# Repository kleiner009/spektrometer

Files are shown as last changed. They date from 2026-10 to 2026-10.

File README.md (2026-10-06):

# Spektrometer für Leuchtmittel

Ein Demo-Spektrometer für den Unterricht, gebaut aus einem Raspberry Pi 5, einer Monochrom-Kamera ohne IR-Filter und einem Taschenspektroskop. Es zeigt das Spektrum von Glühlampe, Leuchtstofflampe und LEDs live auf einem Touchdisplay und auf dem Beamer und berechnet **Farbwiedergabeindex Ra, R9 und Farbtemperatur**.

Entstanden für den Lernfeld-Unterricht „Beleuchtungstechnik“ (Elektroniker/-in für Betriebstechnik): Lichtfarbe, Farbwiedergabe, Unterschied zwischen Kolorimeter und Spektralphotometer.

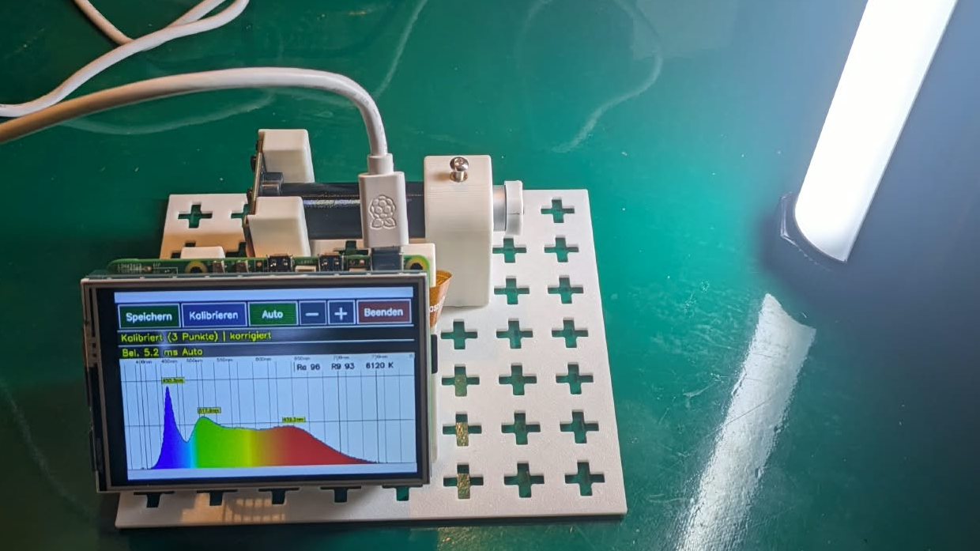
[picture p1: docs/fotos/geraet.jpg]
Spektrometer mit Raspberry Pi 5, Touchdisplay und Taschenspektroskop zeigt das Spektrum einer LED


| Draufsicht | Spaltkappe (Streuscheibe) |
|---|---|
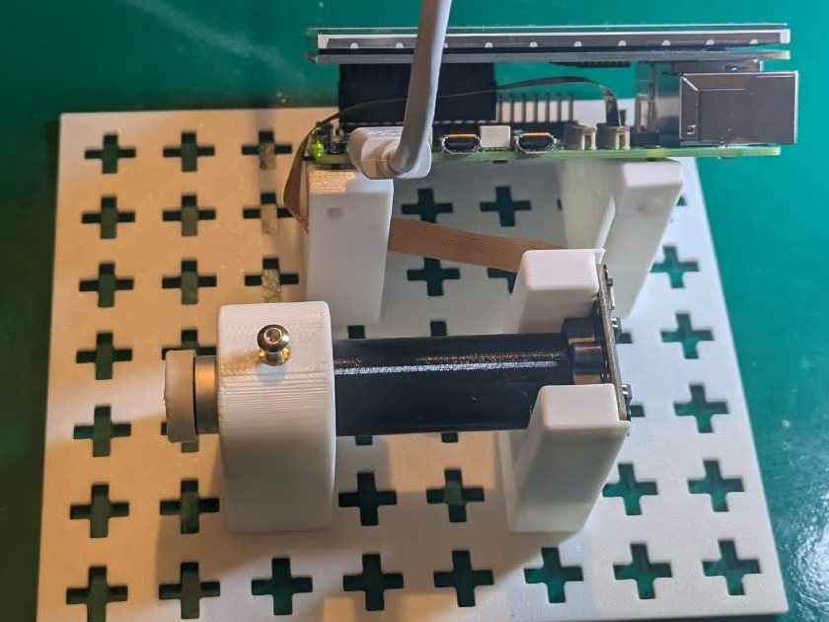
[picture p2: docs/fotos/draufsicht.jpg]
Draufsicht: Spektroskop, Kamera und Raspberry Pi auf der Grundplatte
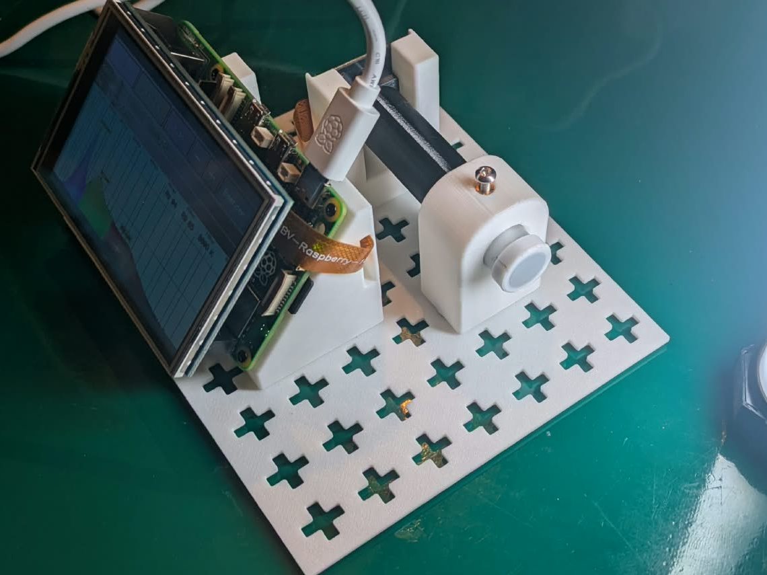
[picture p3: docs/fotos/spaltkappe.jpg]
Weiße Spaltkappe vor dem Taschenspektroskop
|  |  |

## Funktionen

- **Live-Spektrum 360–800 nm**, farbig dargestellt, mit den drei stärksten Maxima
- **Ra, R9 und Farbtemperatur** nach CIE 13.3 (über [colour-science](https://www.colour-science.org/)), als Schätzwert gekennzeichnet
- **Empfindlichkeitskorrektur** mit einer Glühlampe als Referenz (Planck-Strahler)
- **Kalibrier-Assistent** am Touchdisplay mit zwei Methoden für die Wellenlängen: **Leuchtstofflampe** (6 Linien automatisch erkannt, ± 1 nm) oder **Laser + LED**; danach Glühlampe für die Empfindlichkeit
- **Beamer-Ansicht** in Full HD: öffnet sich automatisch, sobald HDMI angesteckt wird
- Belichtung automatisch oder von Hand (0,1 ms bis 1 s), Speichern auf USB-Stick (PNG mit Datum und Maxima)
- Autostart, Bedienung komplett per Touch

## So funktioniert es

```
Lampe → Spaltkappe mit Streuscheibe → Taschenspektroskop (Prisma) → M12-Objektiv → Kamera OV9281 → Raspberry Pi 5
```

Die Streuscheibe vor dem Spalt sorgt dafür, dass Helligkeit und Lage des Spektrums nicht von der Lampenposition abhängen. Die Kamera fotografiert das Spektrum durch das Okular. Das Programm wertet die Kamerazeilen aus, ordnet jeder Spalte eine Wellenlänge zu und korrigiert die Empfindlichkeit des Aufbaus.

**Technische Besonderheiten:**
- Das Messprofil kommt aus den **Sensor-Rohdaten (10 Bit)**, nicht aus dem fertigen Kamerabild. Die Bildverarbeitung des Pi (Farbmatrix, Rauschfilter, Randabschattungs-Korrektur) ist bei schwachen Signalen stark nichtlinear.
- Über **60 Sensorzeilen** gemittelt, das senkt das Rauschen.
- Die Glühlampen-Referenz wird **zweimal belichtet** (kurz für Rot, lang für Blau) und zusammengesetzt, weil eine Glühlampe im Blauen nur wenige Prozent ihrer Rot-Intensität hat.
- **Ohne IR-Sperrfilter** reicht der Messbereich bis über 780 nm (mit Filter endet er bei ≈ 650 nm).

## Wie genau ist das?

Für Vergleiche im Unterricht gut geeignet, **kein Messgerät** im Sinne einer Prüfung.

| Lichtquelle | Nennwert | gemessen | Ra |
|---|---|---|---|
| Energiesparlampe Philips Genie 18 W warmweiß | 2700 K | 2659 K | 84 |
| LED-Lampe | 5500 K | 5509 K | 79 |

Stand 06.10.2026, Kalibrierung mit Leuchtstofflampe. Die Bilder unten stammen noch von der Laser-Kalibrierung (04.10.).

| Glühlampe | LED 5000 K | LED 8500 K |
|---|---|---|
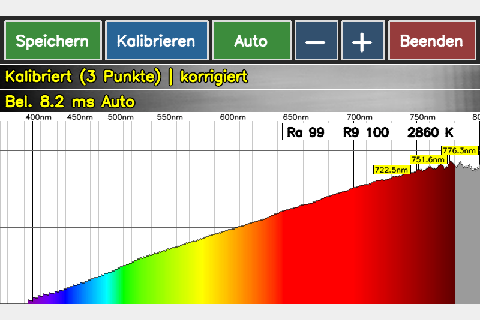
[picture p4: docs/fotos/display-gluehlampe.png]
Spektrum Glühlampe
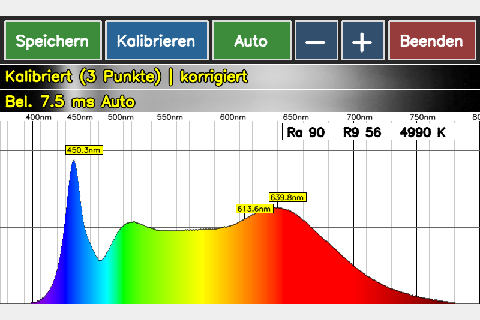
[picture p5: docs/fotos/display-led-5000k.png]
Spektrum LED 5000 K
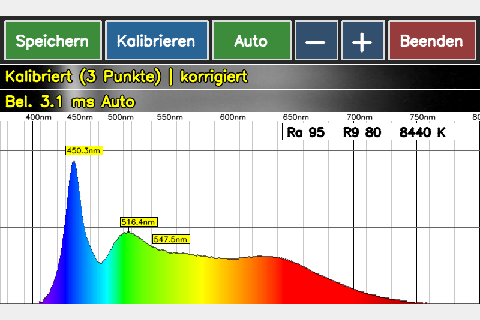
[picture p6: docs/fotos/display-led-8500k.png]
Spektrum LED 8500 K
|  |  |  |

**Beamer-Ansicht (Full HD):**

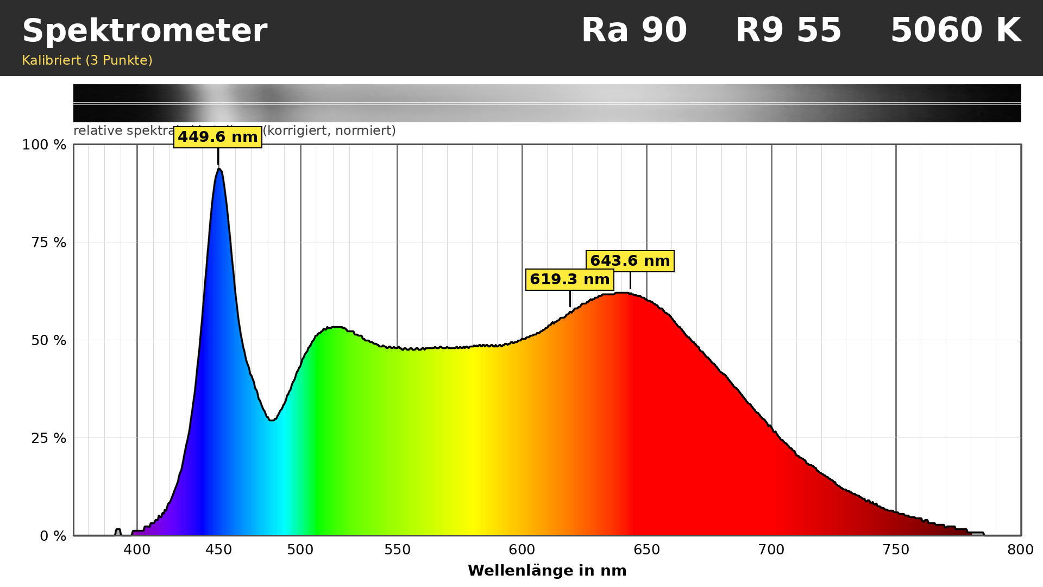
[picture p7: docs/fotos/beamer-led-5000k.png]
Beamer-Ansicht mit dem Spektrum einer 5000-K-LED


- Wellenlängenauflösung: einige Nanometer (Taschenspektroskop + Kamera)
- **Wellenlängen:** Mit der Leuchtstofflampe liegen alle 6 Linien (405–709 nm) auf ± 1,1 nm. Unterhalb 405 nm und oberhalb 710 nm wird extrapoliert.
- **Laser-Wellenlängen nie ungeprüft annehmen:** Unser „532-nm“-Laser lag laut Leuchtstofflampe bei ≈ 513 nm (Diodenlaser). Mit der falschen Annahme zeigte das Gerät im Grün/Gelb bis zu 20 nm daneben.
- **Temperatur der Referenz-Glühlampe:** Sie ist meist unbekannt und bestimmt die ganze Empfindlichkeitskorrektur. Unsere 200-W-Lampe strahlt wie ≈ 2060 K (Abgleich: Energiesparlampe 2700 K und LED 5500 K stimmen damit beide auf ≈ 2 %). Mit den üblichen 2850 K zeigte das Gerät die LED bei fast 30 000 K. Voreinstellung: `GLUEHLAMPE_K` in `software/kalibrierung.py`; bei einer anderen Lampe mit einer Lampe bekannter Farbtemperatur prüfen.
- **Kein Tageslicht** bei der Glühlampen-Messung: Fremdlicht vom Fenster verfälscht die Korrektur stark.
- **Winkel beachten:** Viele LED-Leuchten strahlen je nach Richtung unterschiedliches Licht ab (bei der 8500-K-Leuchte schwankte die Anzeige zwischen ≈ 8500 und über 13 000 K). Lampen für Vergleiche immer gleich ausrichten.

## Nachbauen

1. **Teile besorgen:** siehe [KAUFLISTE.md](KAUFLISTE.md)
2. **Drucken:** Grundplatte, Halter und Spaltkappe, siehe [hardware/](hardware/)
3. **Raspberry Pi OS installieren** (64 Bit, mit Desktop, Trixie oder Bookworm), SSH/WLAN nach Bedarf
4. **Software installieren:**
   ```bash
   git clone https://github.com/kleiner009/spektrometer.git
   cd spektrometer
   ./install.sh
   sudo reboot
   ```
   Das Skript installiert die Pakete, legt `~/Spektrometer` mit einer Python-Umgebung an, trägt nach Rückfrage Kamera und Display in `/boot/firmware/config.txt` ein und richtet Autostart, Fensterregeln, Bildschirmprofile und eine Desktop-Verknüpfung ein.
5. **Touch kalibrieren** (falls nötig): `software/touch_kalibrierung.py` liefert die Matrix für `~/.config/labwc/rc.xml`
6. **Kalibrieren** (siehe unten)

## Kalibrieren

Taste **„Kalibrieren“** am Display. Zuerst wird die Methode für die Wellenlängen gewählt.

**Leuchtstofflampe (empfohlen, 5 Schritte):**

1. **Bildausschnitt:** Weißes Licht vor den Spalt, der grüne Rahmen markiert das Spektrum, dann „Übernehmen“.
2. **Leuchtstofflampe:** Energiesparlampe (Dreibanden-Leuchtstoff) ≥ 3 min vorher einschalten und vor den Spalt stellen, „Messen“. Der Assistent belichtet kurz und lang, erkennt die Linien Hg 405/436, Tb 488, Hg 546, Eu 611/709 nm selbst, prüft die Spiegelung und zeigt den Restfehler je Linie (gut: ≤ 1,5 nm).
3. **Kontrolle (optional):** Laser vor den Spalt; angezeigt wird nur, welche Wellenlänge die neue Achse ihm gibt.
4. **Glühlampe** (siehe unten), 5. **Speichern.**

**Laser + LED (6 Schritte):** 1 Bildausschnitt · 2 grüner Laser · 3 roter Laser · 4 Blauspitze einer weißen LED (optional) · 5 Glühlampe · 6 Speichern. Die Laser-Wellenlängen sind am Gerät einstellbar; Voreinstellung `LASER_GRUEN_NM`/`LASER_ROT_NM` in `software/kalibrierung.py`.

**Glühlampe:** klare Glühlampe ohne Dimmer, 15–20 cm Abstand, **Rollo zu**. Die Belichtung wird für zwei Messungen automatisch gewählt. „Übereinstimmung lang/kurz“ sollte zwischen 0,8 und 1,25 liegen. Die Farbtemperatur der Lampe ist mit − / + einstellbar (siehe „Wie genau ist das?“).

Gespeichert wird erst im letzten Schritt, die alten Werte werden in `alt/` gesichert.

Nach den Wellenlängen-Schritten **schneidet der Assistent den Bildausschnitt automatisch zu**: Schritt 1 wählt den Rahmen bewusst großzügig, danach wird der Ausschnitt so angepasst, dass 360–800 nm die volle Displaybreite füllen. Die Glühlampe wird bereits im endgültigen Ausschnitt gemessen. (`software/zuschnitt.py` bleibt als Werkzeug für ältere Kalibrierungen.)

## Bedienung

| Taste | Funktion |
|---|---|
| Speichern | PNG des Diagramms (mit Datum und Maxima) auf den USB-Stick |
| Kalibrieren | startet den Kalibrier-Assistenten |
| Auto/Manuell | automatische Belichtung an/aus |
| − / + | Belichtung in Stufen (0,1 ms … 1 s) |
| Beenden | Programm beenden |

Grau gezeichnete Kurventeile liegen außerhalb des kalibrierten Bereichs und gehen nicht in Ra/R9/Farbtemperatur ein.

## Ordner

```
software/   Programm (spektrometer.py, kamera.py, kalibrierung.py, beamer.py, …)
system/     Vorlagen: labwc-Fensterregeln/Touch, kanshi-Bildschirmprofile
hardware/   Druckdateien (3MF, Fusion 360 f3d) und Aufbauhinweise
install.sh  Installation auf dem Raspberry Pi
```

**Unterstützte Kameras:** OV9281 Mono (empfohlen) und OV5647 (Farbe; nur sinnvoll ohne IR-Sperrfilter in Objektiv *und* Halter). Das Modell wird automatisch erkannt (`kamera.py`, Tabelle `SENSOREN`).

## Sicherheit im Unterricht

- **Leuchtstofflampe:** enthält Quecksilber; bei Bruch lüften und Scherben nicht mit dem Staubsauger aufnehmen.
- **Laser:** nur Laserklasse 1 oder 2 (< 1 mW), nie in Augen oder auf spiegelnde Flächen richten.
- **Glühlampe:** wird heiß; Abstand halten, Halter aus PETG (nicht PLA) drucken.

## Lizenz und Dank

Apache License 2.0, siehe [LICENSE](LICENSE) und [NOTICE](NOTICE).

Die Software baut auf **[PySpectrometer2](https://github.com/leswright1977/PySpectrometer2) von Les Wright** auf (Apache-2.0). Geänderte Dateien tragen einen Änderungshinweis im Kopf.

Projektseite: [johannes-roeding.de/spektrometer](https://johannes-roeding.de/spektrometer)

---

*Werbehinweis: Die Kaufliste enthält Amazon-Partnerlinks (mit \* markiert). Als Amazon-Partner verdiene ich an qualifizierten Verkäufen.*

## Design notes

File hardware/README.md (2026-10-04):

# Hardware

## Druckdateien (`druckdateien/`)

| Datei | Inhalt |
|---|---|
| `Spektrometer_01-Grundplatte.3mf` | Grundplatte, trägt alle Halter |
| `Spektrometer_01-Halter-Spektroskop.3mf` | Halter für das Taschenspektroskop |
| `Spektrometer_01-Kamerahalter.3mf` | Halter für die Kamera OV9281 mit M12-Objektiv |
| `Spektrometer_01-RasPi-Halter.3mf` | Halter für den Raspberry Pi 5 mit Display |
| `Spektrometer_01-Spaltkappe.3mf` | Spaltkappe mit Aufnahme für die Streuscheibe |
| `Spektrometer_01-Tunnel.3mf` | Lichttunnel zwischen Lampe und Spaltkappe |
| `Spektrometer_01-All.3mf` | alle Teile zusammen auf einer Druckplatte |
| `Spektrometer_01-All.f3d` | Fusion-360-Konstruktion aller Teile (zum Anpassen, z. B. für eine andere Kamera) |

## Stückliste Kleinteile

| Teil | Anzahl |
|---|---|
| Gewindeeinsatz M3 (z. B. ruthex RX-M3x5.7) | 9 |
| Gewindeeinsatz M2 (z. B. ruthex RX-M2x4) | 8 |
| Senkkopfschraube M3 × 10, Innensechskant | 8 |
| Linsen-/Pilzkopfschraube M3 × 12, Innensechskant | 1 |
| Linsenkopfschraube M2 × 10, Innensechskant | 8 |

Die Gewindeeinsätze werden mit dem Lötkolben eingeschmolzen. Bezugsquellen siehe [KAUFLISTE.md](../KAUFLISTE.md).

**Druckeinstellungen:** PETG schwarz matt (wärmefest wegen der Glühlampe, streulichtarm), Schichthöhe 0,2 mm, mindestens 3 Wände, Füllung ≥ 30 %.

**Ausnahme Spaltkappe:** aus **weißem PLA** auf einer **glatten, unstrukturierten Druckplatte** drucken, **erste Schicht 0,1 mm**. Die Kappe wirkt als Streuscheibe vor dem Spalt und muss das Licht gleichmäßig durchlassen. Eine strukturierte Platte oder eine dickere erste Schicht verschlechtern das. PLA wird ab etwa 55 °C weich, deshalb die Glühlampe beim Kalibrieren nicht direkt an die Kappe halten.

## Hinweise zum Aufbau

- **Streuscheibe vor dem Spalt ist Pflicht.** Ohne sie hängen Helligkeit und Lage des Spektrums stark von der Lampenposition ab.
- **Kamera mittig und dicht vor das Okular** setzen und auf das Spektrum scharfstellen.
- **Kamerakabel zugentlasten.** Ein gelöstes Flachbandkabel zeigt sich als „Camera frontend has timed out“.
- **Streulicht vermeiden:** Fällt Licht am Spektroskop vorbei auf die Kamera, erscheint im Bild ein heller Fleck neben dem Spektrum und verfälscht die Messung. Übergang Spektroskop → Kamera abdunkeln.

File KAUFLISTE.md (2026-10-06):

# Kaufliste

Genau diese Teile stecken im Original-Aufbau. Preise schwanken (Stand: 06.10.2026).

> **Werbehinweis:** Die mit \* markierten Links sind Amazon-Partnerlinks (Werbelinks). Als Amazon-Partner verdiene ich an qualifizierten Verkäufen. Für dich ändert sich der Preis dadurch nicht.

## Elektronik

| Teil | Hinweis | ca. € | Link |
|---|---|---|---|
| Raspberry Pi 5 (2 GB) Starter-Set | enthält Netzteil 27 W, 64-GB-microSD, Micro-HDMI-Kabel und Kühlung; das Gehäuse wird nicht gebraucht | 138 | [Amazon\*](https://www.amazon.de/dp/B0DV2F9R16?tag=johannesroe08-21) |
| Touchdisplay 3,5" (AZDelivery, 480 × 320, ILI9486 + XPT2046) | **5er-Pack**; zum Stand 04.10.2026 nicht lieferbar, gleichwertige Displays über die Suche | – | [Amazon\*](https://www.amazon.de/dp/B0CN9L2TBY?tag=johannesroe08-21) · [Suche\*](https://www.amazon.de/s?k=3%2C5+Zoll+Touch+Display+Raspberry+Pi+480x320&tag=johannesroe08-21) |
| Kamera innomaker OV9281 Mono, Global Shutter | **inklusive Objektiv, ohne IR-Sperrfilter**; kein zusätzliches Objektiv nötig | 30 | [Amazon\*](https://www.amazon.de/dp/B09WTP5GZH?tag=johannesroe08-21) |
| USB-Stick | optional, zum Speichern der Messungen | 6 | [Amazon\*](https://www.amazon.de/s?k=USB+Stick+16GB&tag=johannesroe08-21) |

## Optik und Kalibrierung

| Teil | Hinweis | ca. € | Link |
|---|---|---|---|
| Taschenspektroskop 55 mm („Juwelier-Spektroskop“) | Geradsicht-Prismenspektroskop mit Spalt | 36 | [Amazon\*](https://www.amazon.de/dp/B0788TLD1T?tag=johannesroe08-21) |
| Energiesparlampe Philips Genie 18 W E27, warmweiß | **Wellenlängen-Kalibrierung** (Linien 405–709 nm); jede Dreibanden-Energiesparlampe geht | 8 | [Amazon\*](https://www.amazon.de/dp/B0094DY2CG?tag=johannesroe08-21) |
| Laserpointer grün | optional (Methode „Laser + LED“ oder Kontrolle). **Wellenlänge prüfen:** unser „532-nm“-Laser hatte ≈ 513 nm. **Nur Laserklasse 1/2 (< 1 mW)**, nie in Augen richten | 10 | [Amazon\*](https://www.amazon.de/s?k=Laserpointer+gr%C3%BCn+532nm+Klasse+2&tag=johannesroe08-21) |
| Laserpointer rot, 650 nm | optional, ebenfalls Klasse 1/2 | 8 | [Amazon\*](https://www.amazon.de/s?k=Laserpointer+rot+650nm+Klasse+2&tag=johannesroe08-21) |
| Glühlampe 100–200 W, klar, E27 + Fassung | Referenz für die Empfindlichkeitskorrektur; ohne Dimmer betreiben; Farbtemperatur mit einer bekannten Lampe abgleichen | 5–10 | [Amazon\*](https://www.amazon.de/s?k=Gl%C3%BChbirne+100W+E27+klar&tag=johannesroe08-21) |
| Weiße LED (z. B. Handylicht) | nur Methode „Laser + LED“: Blauspitze ≈ 450 nm | – | vorhanden |

## Mechanik (3D-Druck)

| Teil | Bedarf | Packung | ca. € | Link |
|---|---|---|---|---|
| PLA-Filament weiß, 1,75 mm | nur für die Spaltkappe (Streuscheibe) | 1 kg | 20 | [Amazon\*](https://www.amazon.de/s?k=PLA+Filament+wei%C3%9F+1%2C75&tag=johannesroe08-21) |
| PETG-Filament schwarz, matt, 1,75 mm | laut Slicer | 1 kg | 20 | [Amazon\*](https://www.amazon.de/s?k=PETG+Filament+schwarz+matt+1%2C75&tag=johannesroe08-21) |
| Gewindeeinsatz M3 (ruthex RX-M3x5.7) | **9 Stück** | 100 | 9 | [Amazon\*](https://www.amazon.de/dp/B08BCRZZS3?tag=johannesroe08-21) |
| Gewindeeinsatz M2 (ruthex RX-M2x4) | **8 Stück** | 70 | 9 | [Amazon\*](https://www.amazon.de/dp/B088QJG676?tag=johannesroe08-21) |
| Senkkopfschraube M3 × 10, Innensechskant | **8 Stück** | 50 | 5 | [Amazon\*](https://www.amazon.de/dp/B0GDY545LD?tag=johannesroe08-21) |
| Linsen-/Pilzkopfschraube M3 × 12, Innensechskant | **1 Stück** | 70 | 6 | [Amazon\*](https://www.amazon.de/dp/B0FW4H74J7?tag=johannesroe08-21) |
| Linsenkopfschraube M2 × 10, Innensechskant | **8 Stück** | 50 | 8 | [Amazon\*](https://www.amazon.de/dp/B01E5EOLJC?tag=johannesroe08-21) |

**Gesamt:** rund 290 € ohne Display und ohne bereits Vorhandenes (Drucker, Werkzeug, Lötkolben zum Einschmelzen der Gewindeeinsätze). Von Schrauben und Einsätzen bleibt reichlich übrig.

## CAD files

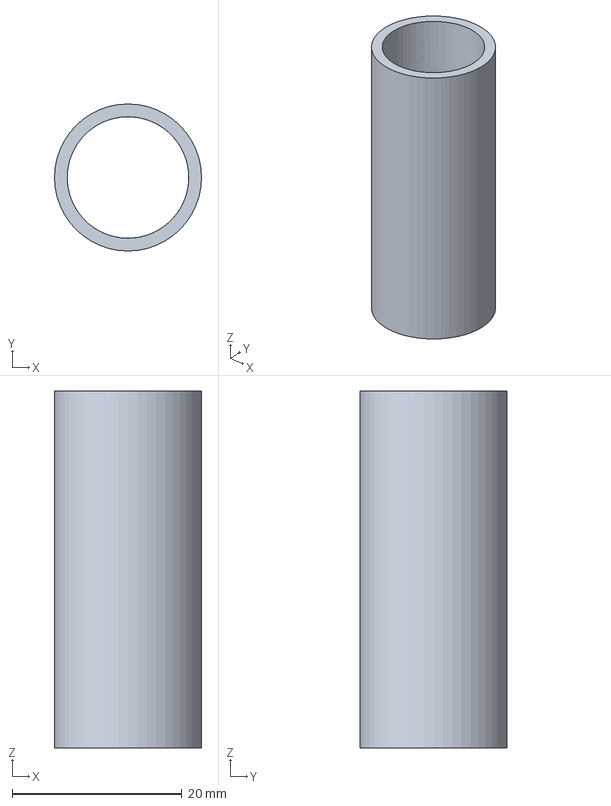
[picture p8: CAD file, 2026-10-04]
hardware/druckdateien/Spektrometer_01-Tunnel.3mf
17.3 x 17.3 x 42.0 mm

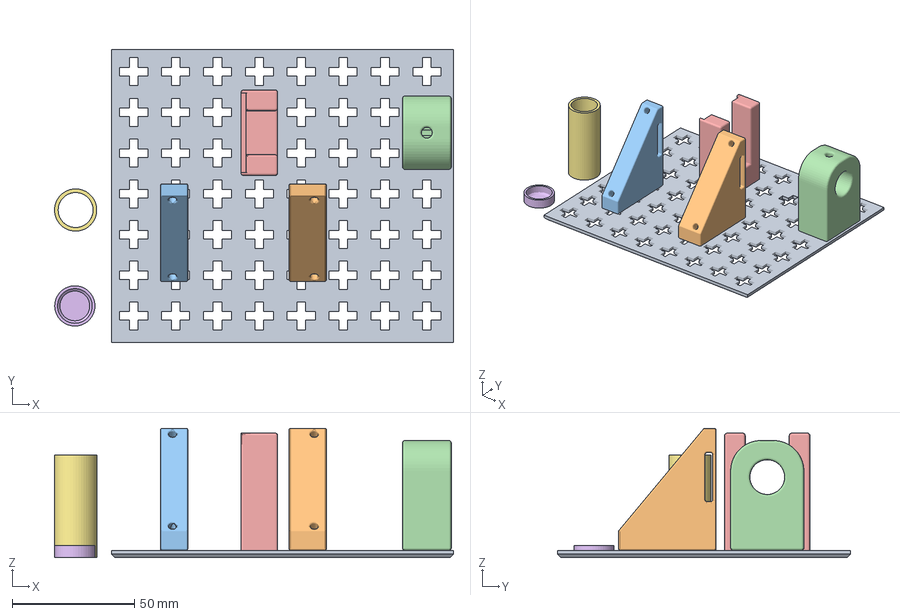
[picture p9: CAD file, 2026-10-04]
hardware/druckdateien/Spektrometer_01-All.3mf
163.3 x 120.0 x 53.0 mm
Körper3
Körper4
Körper5
Körper6
Körper7
Körper8
Körper9

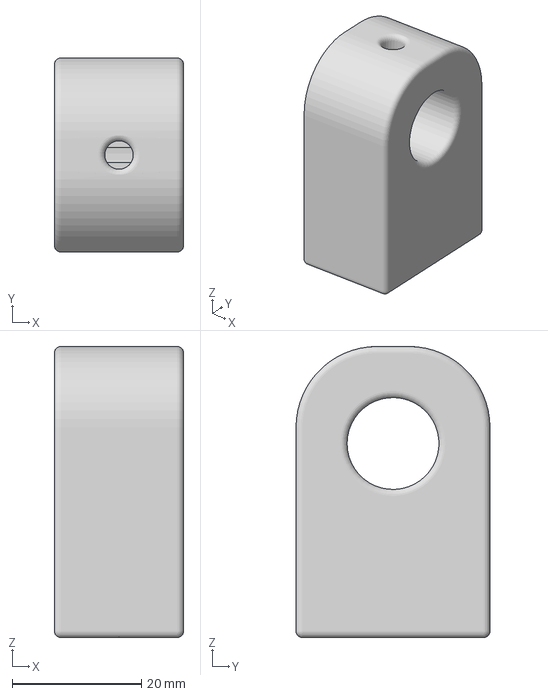
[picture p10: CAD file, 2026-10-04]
hardware/druckdateien/Spektrometer_01-Halter-Spektroskop.3mf
20.0 x 30.0 x 45.0 mm

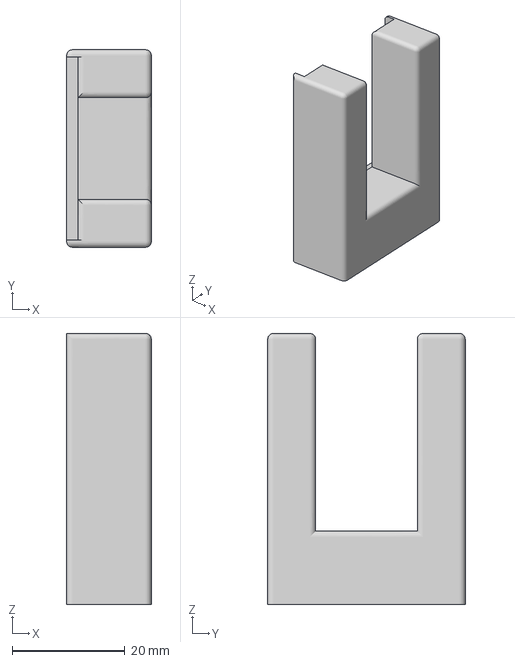
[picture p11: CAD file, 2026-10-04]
hardware/druckdateien/Spektrometer_01-Kamerahalter.3mf
15.0 x 35.0 x 48.0 mm

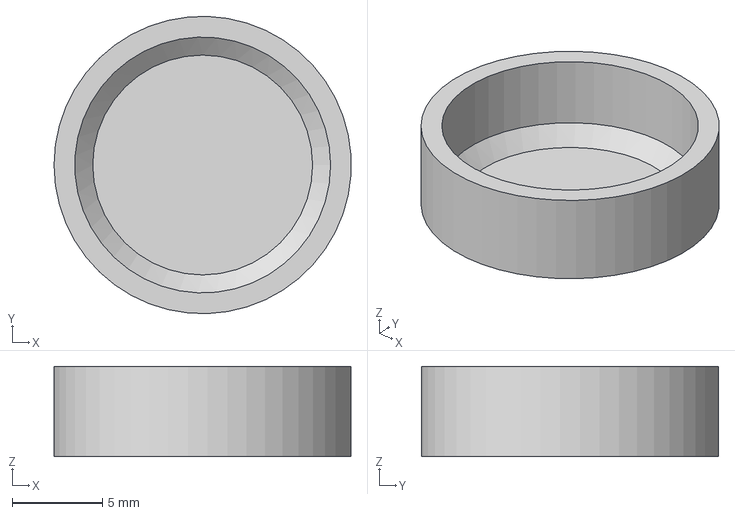
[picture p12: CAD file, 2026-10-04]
hardware/druckdateien/Spektrometer_01-Spaltkappe.3mf
16.5 x 16.5 x 5.00 mm

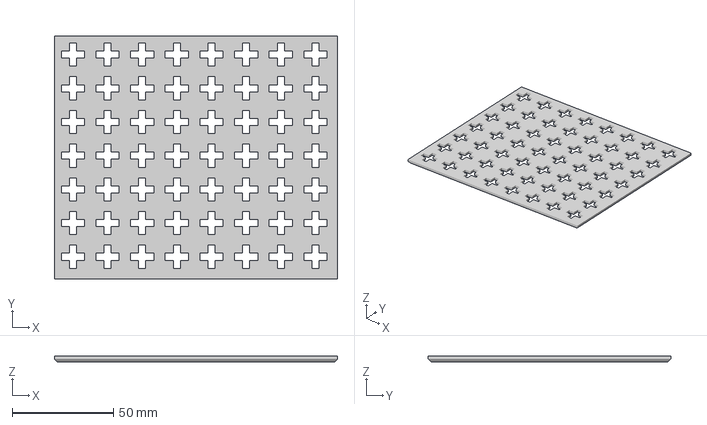
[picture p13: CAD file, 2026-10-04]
hardware/druckdateien/Spektrometer_01-Grundplatte.3mf
140.0 x 120.0 x 3.00 mm

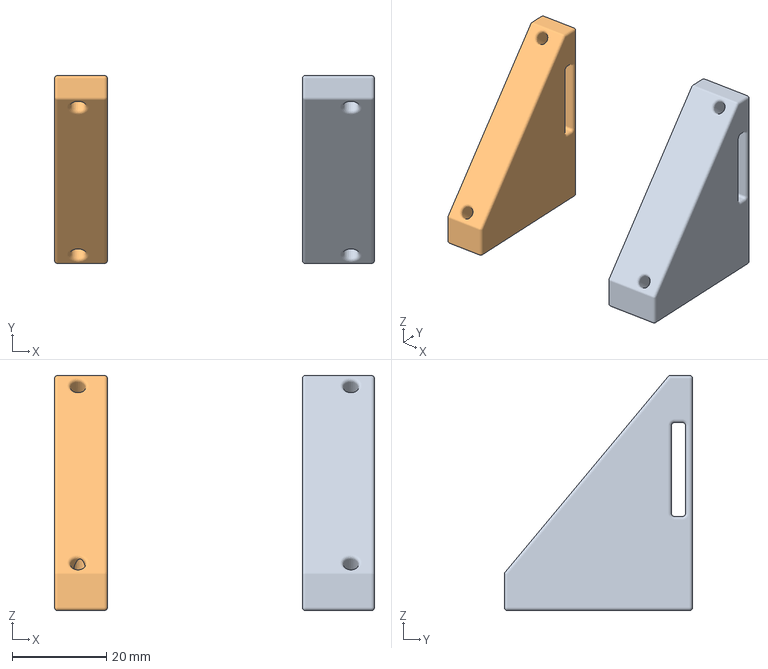
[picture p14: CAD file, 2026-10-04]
hardware/druckdateien/Spektrometer_01-RasPi-Halter.3mf
68.0 x 40.0 x 50.0 mm
Körper4
Körper5

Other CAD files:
hardware/druckdateien/Spektrometer_01-All.f3d

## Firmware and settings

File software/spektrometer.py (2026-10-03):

#!/usr/bin/env python3
# ---------------------------------------------------------------------------
# GEAENDERTE DATEI (Apache-2.0, Abschnitt 4b)
# Basis: PySpectrometer2 von Les Wright (https://github.com/leswright1977/PySpectrometer2),
# Apache License 2.0. Geaendert 2026 von Johannes Roeding fuer das Projekt
# "Spektrometer fuer Leuchtmittel" (https://github.com/kleiner009/spektrometer):
# Touch-Bedienung, Messung aus Sensor-Rohdaten, Empfindlichkeitskorrektur,
# Ra/R9/CCT, Kalibrier-Assistent, Beamer-Ansicht, deutsche Oberflaeche.
# ---------------------------------------------------------------------------

'''
PySpectrometer2 Les Wright 2022
https://www.youtube.com/leslaboratory
https://github.com/leswright1977

This project is a follow on from: https://github.com/leswright1977/PySpectrometer 

This is a more advanced, but more flexible version of the original program. Tk Has been dropped as the GUI to allow fullscreen mode on Raspberry Pi systems and the iterface is designed to fit 800*480 screens, which seem to be a common resolutin for RPi LCD's, paving the way for the creation of a stand alone benchtop instrument.

Whats new:
Higher resolution (800px wide graph)
3 row pixel averaging of sensor data
Fullscreen option for the Spectrometer graph
3rd order polymonial fit of calibration data for accurate measurement.
Improved graph labelling
Labelled measurement cursors
Optional waterfall display for recording spectra changes over time.
Key Bindings for all operations

All old features have been kept, including peak hold, peak detect, Savitsky Golay filter, and the ability to save graphs as png and data as CSV.

For instructions please consult the readme!
'''


import cv2
import time
import numpy as np
from specFunctions import wavelength_to_rgb,savitzky_golay,peakIndexes,readcal,writecal,background,generateGraticule
import base64
import argparse
import os
import sys
import subprocess
import glob
import warnings
warnings.filterwarnings("ignore")  # colour-science meldet fehlendes SciPy/Matplotlib, wird nicht gebraucht
try:
	import colour  # colour-science, liegt im venv ~/Spektrometer/venv
	COLOUR_OK = True
except ImportError:
	COLOUR_OK = False
import kamera  # gemeinsame Kameraeinstellungen (Zuschnitt, Spiegeln, linear, Weissabgleich)
import beamer  # hochaufgeloeste Ansicht fuer Beamer/Monitor an HDMI

parser = argparse.ArgumentParser()
group = parser.add_mutually_exclusive_group()
group.add_argument("--fullscreen", help="Fullscreen (Native 800*480)",action="store_true")
group.add_argument("--waterfall", help="Enable Waterfall (Windowed only)",action="store_true")
args = parser.parse_args()
dispFullscreen = False
dispWaterfall = False
if args.fullscreen:
	print("Fullscreen Spectrometer enabled")
	dispFullscreen = True
if args.waterfall:
	print("Waterfall display enabled")
	dispWaterfall = True
	
	

frameWidth = 800
frameHeight = 600

#need to spend more time at: https://datasheets.raspberrypi.com/camera/picamera2-manual.pdf
#but this will do for now!
#min and max microseconds per frame gives framerate.
#30fps (33333, 33333)
#25fps (40000, 40000)

picamGain = 4.0

# --- Anpassung Spektrometer (Johannes, 2026-09-25) ---------------------------
# Zuschnitt, Spiegeln, Weissabgleich und lineare Kennlinie stehen in kamera.py.
BELICHTUNG_US = 60000  # feste Belichtungszeit (Automatik aus), mit t/g Gain anpassen
GLAETTUNG_FENSTER = 21  # Savitzky-Golay-Fenster (ungerade), groesser = glatter
GLAETTUNG_ORDNUNG = 3   # Polynomgrad des Filters, kleiner = glatter
ZEITMITTEL = 0.6        # Anteil des alten Spektrums je Bild (0 = aus), beruhigt Flackern
ANZAHL_MAXIMA = 3       # so viele staerkste Maxima werden beschriftet
MIN_SIGNAL = 6          # unterhalb dieser Rohsignal-Hoehe wird die Kurve nicht normiert
picam2 = kamera.kamera_starten(BELICHTUNG_US, picamGain, max_bilddauer_us=1050000)  # Belichtung bis 1 s
belichtung_soll = BELICHTUNG_US  # wird automatisch nachgefuehrt (siehe Hauptschleife)

#Change analog gain
#picam2.set_controls({"AnalogueGain": 10.0}) #Default 1
#picam2.set_controls({"Brightness": 0.2}) #Default 0 range -1.0 to +1.0
#picam2.set_controls({"Contrast": 1.8}) #Default 1 range 0.0-32.0



title1 = 'PySpectrometer 2 - Spectrograph'
title2 = 'PySpectrometer 2 - Waterfall'
stackHeight = 320+80+80 #height of the displayed CV window (graph+preview+messages)

if dispWaterfall == True:
	#watefall first so spectrum is on top
	cv2.namedWindow(title2,cv2.WINDOW_GUI_NORMAL)
	cv2.resizeWindow(title2,frameWidth,stackHeight)
	cv2.moveWindow(title2,200,200);

if dispFullscreen == True:
	cv2.namedWindow(title1,cv2.WND_PROP_FULLSCREEN)
	cv2.setWindowProperty(title1,cv2.WND_PROP_FULLSCREEN,cv2.WINDOW_FULLSCREEN)
else:
	cv2.namedWindow(title1,cv2.WINDOW_GUI_NORMAL)
	cv2.resizeWindow(title1,frameWidth,stackHeight)
	cv2.moveWindow(title1,0,0);

#settings for peak detect
savpoly = 7 #savgol filter polynomial max val 15
mindist = 50 #minumum distance between peaks max val 100
thresh = 20 #Threshold max val 100

calibrate = False

clickArray = [] 
cursorX = 0
cursorY = 0
# Buttonleiste statt Banner: (Name, x0, x1) in Bildkoordinaten, Hoehe 80 px
BUTTONS = [("speichern", 8, 168, "Speichern"), ("kalibrieren", 176, 346, "Kalibrieren"),
           ("auto", 354, 484, "Auto"), ("dunkler", 492, 562, "-"), ("heller", 570, 640, "+"),
           ("beenden", 648, 792, "Beenden")]
# Belichtung: Auto (Nachfuehrung) oder von Hand in festen Stufen
STUFEN_US = [100, 200, 500, 1000, 2000, 5000, 10000, 20000, 50000, 100000, 200000, 500000, 1000000]
belichtung_auto = True
aussteuerung = 0  # hellster Kanal in der Bandmitte (fuer Uebersteuerungswarnung)
aktion = None

def handle_mouse(event,x,y,flags,param):
	global clickArray
	global cursorX
	global cursorY
	global aktion
	mouseYOffset = 160
	if event == cv2.EVENT_MOUSEMOVE:
		cursorX = x
		cursorY = y	
	if event == cv2.EVENT_LBUTTONDOWN:
		if y < 80:
			for name, x0, x1, _ in BUTTONS:
				if x0 <= x <= x1:
					aktion = name
			return
		mouseX = x
		mouseY = y-mouseYOffset
		clickArray.append([mouseX,mouseY])
#listen for click on plot window
cv2.setMouseCallback(title1,handle_mouse)


font=cv2.FONT_HERSHEY_SIMPLEX

intensity = [0] * frameWidth #array for intensity data...full of zeroes

holdpeaks = False #are we holding peaks?
measure = False #are we measuring?
recPixels = False #are we measuring pixels and recording clicks?


#messages
msg1 = ""
saveMsg = ""

#blank image for Waterfall
waterfall = np.zeros([320,frameWidth,3],dtype=np.uint8)
waterfall.fill(0) #fill black

#Go grab the computed calibration data
caldata = readcal(frameWidth)
wavelengthData = caldata[0]
calmsg1 = caldata[1]
calmsg2 = caldata[2]
calmsg3 = caldata[3]

#generate the craticule data
graticuleData = generateGraticule(wavelengthData)
tens = (graticuleData[0])
fifties = (graticuleData[1])

def usb_ziel():
	# erster beschreibbarer, eingehaengter USB-Stick (Desktop haengt unter /media/<user>/ ein)
	for d in sorted(glob.glob('/media/*/*')):
		if os.path.ismount(d) and os.access(d, os.W_OK):
			return d
	return None

def auf_usb_speichern(graph, maxima_nm):
	ziel = usb_ziel()
	if ziel is None:
		return "Kein USB-Stick gefunden!"
	jetzt = time.strftime("%Y-%m-%d %H:%M:%S")
	kopf = np.full([30, graph.shape[1], 3], 255, dtype=np.uint8)
	text = "Spektrum " + jetzt
	if maxima_nm:
		text += "   Maxima: " + ", ".join(str(w) + " nm" for w in maxima_nm)
	cv2.putText(kopf, text, (8, 20), font, 0.5, (0, 0, 0), 1, cv2.LINE_AA)
	bild = np.vstack((kopf, graph))
	name = "spektrum-" + time.strftime("%Y%m%d-%H%M%S") + ".png"
	try:
		cv2.imwrite(os.path.join(ziel, name), bild)
		os.sync()  # sicher auf den Stick schreiben, bevor er abgezogen wird
	except Exception as e:
		print("Speichern fehlgeschlagen:", e)
		return "Speichern fehlgeschlagen!"
	return "Gespeichert: " + name

def buttonleiste(meldung):
	leiste = np.full([80, frameWidth, 3], 40, dtype=np.uint8)
	for name, x0, x1, beschriftung in BUTTONS:
		farbe = {"speichern": (60, 140, 60), "kalibrieren": (150, 100, 40),
		         "dunkler": (110, 80, 50), "heller": (110, 80, 50)}.get(name, (60, 60, 150))
		if name == "auto":
			beschriftung = "Auto" if belichtung_auto else "Manuell"
			farbe = (60, 140, 60) if belichtung_auto else (90, 90, 90)
		cv2.rectangle(leiste, (x0, 8), (x1, 72), farbe, -1)
		cv2.rectangle(leiste, (x0, 8), (x1, 72), (220, 220, 220), 2)
		gross = name in ("dunkler", "heller")
		(tw, th), _ = cv2.getTextSize(beschriftung, font, 1.6 if gross else 0.8, 3 if gross else 2)
		cv2.putText(leiste, beschriftung, (x0 + (x1 - x0 - tw) // 2, 40 + th // 2), font,
		            1.6 if gross else 0.8, (255, 255, 255), 3 if gross else 2, cv2.LINE_AA)
	return leiste

def status_einblenden(bild, meldung):
	"""Statuszeilen gross in den dunklen Kamerastreifen (Zeilen 80-160) schreiben."""
	ms = belichtung_soll / 1000
	kurve = "korrigiert" if EMPFINDLICHKEIT is not None else "unkorrigiert"
	zeile1 = [(calmsg1 + " | " + kurve, (0, 255, 255))]
	zeile2 = [("Bel. %s ms %s" % (("%.1f" % ms) if ms < 10 else "%d" % ms,
	                              "Auto" if belichtung_auto else "manuell"), (0, 255, 255))]
	if aussteuerung >= 250:
		zeile2.append(("  UEBERSTEUERT!", (60, 60, 255)))
	elif meldung:
		zeile2.append(("  " + ("Gespeichert" if meldung.startswith("Gespeichert") else meldung[:26]), (120, 255, 120)))
	# Hilfslinien liegen bei y 118/122: Zeile 1 darueber, Zeile 2 darunter
	for y, teile in ((108, zeile1), (150, zeile2)):
		x = 8
		for text, farbe in teile:
			cv2.putText(bild, text, (x, y), font, 0.8, (0, 0, 0), 5, cv2.LINE_AA)
			cv2.putText(bild, text, (x, y), font, 0.8, farbe, 2, cv2.LINE_AA)
			x += cv2.getTextSize(text, font, 0.8, 2)[0][0]

mittel = None
maxima_nm = []
beamer_fenster = None   # (Fenstername, Breite, Hoehe) solange ein HDMI-Geraet angeschlossen ist
letzte_hdmi_pruefung = 0.0
hdmi_kandidat = None  # letztes Pruefergebnis; geoeffnet wird erst bei zweimal gleichem Ergebnis
beamer_vollbild_ab = None  # Zeitpunkt, ab dem das Beamer-Fenster auf Vollbild geschaltet wird
bilder_gezaehlt, fps_start = 0, time.time()

def beamer_verwalten():
	"""HDMI pruefen: Beamer-Fenster oeffnen/schliessen (Fenstertitel steuert per labwc-Regel den Ausgang)."""
	global beamer_fenster, hdmi_kandidat, beamer_vollbild_ab
	ausgang = beamer.hdmi_ausgang()
	stabil = ausgang == hdmi_kandidat
	hdmi_kandidat = ausgang
	if not stabil:
		return  # Ausgang wird gerade eingerichtet (kanshi) -> naechste Pruefung abwarten
	if ausgang is None:
		if beamer_fenster is not None:
			cv2.destroyWindow(beamer_fenster[0])
			beamer_fenster = None
		return
	name = "Spektrometer Beamer " + ausgang[0]
	if beamer_fenster is not None and beamer_fenster[0] == name and beamer_fenster[3:] == (ausgang[1], ausgang[2]):
		return  # gleicher Ausgang, gleiche Aufloesung
	if beamer_fenster is not None:
		cv2.destroyWindow(beamer_fenster[0])
	w, h = beamer.zeichengroesse(ausgang[1], ausgang[2])
	# Die labwc-Fensterregel ("Spektrometer Beamer HDMI-A-x" -> MoveToOutput) legt das
	# Fenster auf den HDMI-Ausgang. Vollbild erst danach (s. Hauptschleife): Qt waehlt
	# fuer Vollbild den Bildschirm, auf dem das Fenster gerade liegt - direkt beim
	# Oeffnen waere das noch das 3,5"-Display.
	cv2.namedWindow(name, cv2.WINDOW_NORMAL | cv2.WINDOW_GUI_NORMAL)
	cv2.resizeWindow(name, w, h)
	beamer_vollbild_ab = time.time() + 1.0
	# (Name, Zeichenbreite, Zeichenhoehe, Ausgangsbreite, Ausgangshoehe)
	beamer_fenster = (name, w, h, ausgang[1], ausgang[2])
	print("Beamer-Ansicht auf", ausgang[0], ":", w, "x", h, "->", ausgang[1], "x", ausgang[2], flush=True)
kennwerte = None
letzte_cri = 0.0

def empfindlichkeit_laden():
	# optionale Korrektur der Kameraempfindlichkeit: CSV "Wellenlaenge,Faktor"
	# (wird spaeter mit einer Halogenlampe als Referenz erzeugt)
	try:
		d = np.loadtxt('empfindlichkeit.csv', delimiter=',', skiprows=1)
		return d[:, 0], d[:, 1]
	except Exception:
		return None

EMPFINDLICHKEIT = empfindlichkeit_laden()

def empfindlichkeit_faktor(wl):
	# nur gueltige Stuetzstellen (Faktor > 0); ausserhalb des gueltigen Bereichs 0.
	# (27.09. kurz Randwert gehalten -- das verstaerkte aber Streulicht jenseits der
	# Bildfeldkante; seit der Kantenerkennung im Assistenten ist der Bereich zuverlaessig.)
	w, f = EMPFINDLICHKEIT
	ok = f > 0
	if ok.sum() < 2:
		return np.ones_like(np.asarray(wl, dtype=float))
	return np.interp(wl, w[ok], f[ok], left=0, right=0)

def anzeige_faktor_und_maske():
	"""Fuer die Anzeige (nicht fuer Ra/CCT): innerhalb des kalibrierten Bereichs der
	Korrekturfaktor, ausserhalb der Randwert (Kurve laeuft weiter statt hart abzubrechen).
	Maske = True im kalibrierten Bereich; ausserhalb wird grau gezeichnet (28.09.)."""
	if EMPFINDLICHKEIT is None:
		return np.ones(len(wavelengthData)), np.ones(len(wavelengthData), dtype=bool)
	w, f = EMPFINDLICHKEIT
	ok = f > 0
	if ok.sum() < 2:
		return np.ones(len(wavelengthData)), np.ones(len(wavelengthData), dtype=bool)
	maske = empfindlichkeit_faktor(wavelengthData) > 0
	return np.interp(wavelengthData, w[ok], f[ok]), maske

ANZEIGE_FAKTOR, ANZEIGE_GUELTIG = anzeige_faktor_und_maske()
anzeige_skala = None

def korrigiert_fuer_anzeige(werte):
	"""Kurve fuer die Anzeige: Sockel abziehen, Empfindlichkeit korrigieren, auf 240 normieren."""
	global anzeige_skala
	werte = np.asarray(werte, dtype=float)
	if EMPFINDLICHKEIT is None:
		return np.clip(werte, 0, 255).astype(int)
	roh = np.clip(werte - np.percentile(werte, 5), 0, None)
	v = roh * ANZEIGE_FAKTOR
	if roh.max() < MIN_SIGNAL:
		# zu wenig Licht: nicht normieren, sonst wird Rauschen zur Scheinkurve aufgeblasen
		return np.clip(roh, 0, 255).astype(int)
	# Skala nur aus dem kalibrierten Bereich (grauer Rand bestimmt die Hoehe nicht)
	skala = 240.0 / max(v[ANZEIGE_GUELTIG].max() if ANZEIGE_GUELTIG.any() else v.max(), 1e-6)
	# Skala beruhigen, damit die Kurve bei Rauschen nicht pumpt
	anzeige_skala = skala if anzeige_skala is None else 0.8 * anzeige_skala + 0.2 * skala
	return np.clip(v * anzeige_skala, 0, 255).astype(int)

def lichtkennwerte(wl, werte):
	"""Ra, R9 und CCT aus dem gemessenen (relativen) Spektrum, CIE 13.3 via colour-science."""
	if not COLOUR_OK:
		return None
	wl = np.asarray(wl, dtype=float)
	v = np.asarray(werte, dtype=float)
	v = np.clip(v - np.percentile(v, 5), 0, None)  # Dunkel-/Streulichtsockel abziehen
	if v.max() < 8:
		return None  # zu wenig Licht fuer eine sinnvolle Rechnung
	if EMPFINDLICHKEIT is not None:
		v = v * empfindlichkeit_faktor(wl)
	reihenfolge = np.argsort(wl)
	wl, v = wl[reihenfolge], v[reihenfolge]
	raster = np.arange(380, 781, 5)
	sd = colour.SpectralDistribution(dict(zip(raster, np.interp(raster, wl, v, left=0, right=0))))
	try:
		spec = colour.colour_rendering_index(sd, additional_data=True)
		xy = colour.XYZ_to_xy(colour.sd_to_XYZ(sd))
		cct = float(colour.xy_to_CCT(xy, method='McCamy 1992'))
	except Exception as e:
		print("CRI-Berechnung fehlgeschlagen:", e)
		return None
	return {"ra": float(spec.Q_a), "r9": float(spec.Q_as[9].Q_a), "cct": cct, "bis_nm": float(wl.max())}

def kennwert_hinweise(k):
	"""Gruende, warum Ra/R9/CCT nur Schaetzwerte sind."""
	hinweise = []
	if k is None:
		return hinweise
	if "UNKAL" in calmsg1.upper():
		hinweise.append("unkalibriert")
	if k["bis_nm"] < 760:
		hinweise.append("nur bis %d nm" % k["bis_nm"])
	if EMPFINDLICHKEIT is None:
		hinweise.append("unkorrigiert")
	return hinweise

def kennwerte_zeichnen(graph, k):
	if k is None:
		return
	text = "Ra %d   R9 %d   %d K" % (round(k["ra"]), round(k["r9"]), round(k["cct"], -1))
	hinweise = kennwert_hinweise(k)
	x0, x1 = 470, 796
	hoehe = 44 if hinweise else 28
	cv2.rectangle(graph, (x0, 18), (x1, 18 + hoehe), (255, 255, 255), -1)
	cv2.rectangle(graph, (x0, 18), (x1, 18 + hoehe), (0, 0, 0), 1)
	cv2.putText(graph, text, (x0 + 8, 40), font, 0.65, (0, 0, 0), 2, cv2.LINE_AA)
	if hinweise:
		cv2.putText(graph, "Schaetzwert: " + ", ".join(hinweise), (x0 + 8, 56), font, 0.4, (0, 0, 180), 1, cv2.LINE_AA)

def snapshot(savedata):
	now = time.strftime("%Y%m%d--%H%M%S")
	timenow = time.strftime("%H:%M:%S")
	imdata1 = savedata[0]
	graphdata = savedata[1]
	if dispWaterfall == True:
		imdata2 = savedata[2]
		cv2.imwrite("waterfall-" + now + ".png",imdata2)
	cv2.imwrite("spectrum-" + now + ".png",imdata1)
	#print(graphdata[0]) #wavelengths
	#print(graphdata[1]) #intensities
	f = open("Spectrum-"+now+'.csv','w')
	f.write('Wavelength,Intensity\r\n')
	for x in zip(graphdata[0],graphdata[1]):
		f.write(str(x[0])+','+str(x[1])+'\r\n')
	f.close()
	message = "Last Save: "+timenow
	return(message)
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

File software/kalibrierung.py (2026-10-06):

#!/usr/bin/env python3
"""Gefuehrte Kalibrierung des Spektrometers am Touchdisplay.

Beim Start wird die Methode fuer die Wellenlaengen gewaehlt:

Leuchtstofflampe (5 Schritte):
  1. Bildausschnitt   - weisses Licht vor den Spalt, Spektrum wird erkannt
  2. Leuchtstofflampe - Linien 405/436/488/546/611/709 nm automatisch erkennen und
                        zuordnen (Ausgleichsparabel), prueft auch die Spiegelung
  3. Kontrolle        - optional: Laser messen, die neue Achse wird nur angezeigt
  4. Gluehlampe       - Normkurve (Planck) fuer die Empfindlichkeitskorrektur
  5. Zusammenfassung  - Speichern oder Verwerfen

Laser + LED (6 Schritte, bisheriger Weg):
  1. Bildausschnitt, 2. gruener Laser (LASER_GRUEN_NM), 3. roter Laser (prueft die
  Spiegelung), 4. LED-Blauspitze (optional), 5. Gluehlampe, 6. Zusammenfassung

Nach den Wellenlaengen wird der Ausschnitt automatisch auf 360-800 nm zugeschnitten.
06.10.2026: Der eigene "gruene Laser" liegt laut Leuchtstofflampe bei ~513 nm, nicht 532 nm.

Gespeichert wird erst im letzten Schritt: kamera_einstellungen.json, caldata.txt,
empfindlichkeit.csv, Protokoll in kalibrierung_protokoll.json. Alte Dateien
werden vorher nach alt/<Zeitstempel>/ gesichert.
Rueckgabewert: 0 = gespeichert, 1 = abgebrochen/verworfen.
"""
import json
import os
import shutil
import sys
import time

import cv2
import numpy as np
from PIL import Image, ImageDraw, ImageFont

import kamera

ORDNER = os.path.dirname(os.path.abspath(__file__))
W, H = 800, 480
FENSTER = "PySpectrometer Kalibrierung"  # beginnt mit PySpectrometer -> labwc legt es aufs Display
SENSOR_W, SENSOR_H = kamera.SENSOR_W, kamera.SENSOR_H
C2 = 1.4388e-2  # zweite Strahlungskonstante in m*K
SCHRIFT = "/usr/share/fonts/truetype/dejavu/DejaVuSans.ttf"
SCHRIFT_FETT = "/usr/share/fonts/truetype/dejavu/DejaVuSans-Bold.ttf"
_schriften = {}


def schrift(groesse, fett=False):
	if (groesse, fett) not in _schriften:
		_schriften[(groesse, fett)] = ImageFont.truetype(SCHRIFT_FETT if fett else SCHRIFT, groesse)
	return _schriften[(groesse, fett)]


# --------------------------------------------------------------------------- Oberflaeche
class Oberflaeche:
	"""Vollbildfenster 800x480 mit Titel, Anleitung, Inhaltsbereich und Touch-Buttons."""
	INHALT = (0, 128, W, 396)  # x0, y0, x1, y1

	def __init__(self):
		cv2.namedWindow(FENSTER, cv2.WND_PROP_FULLSCREEN)
		cv2.setWindowProperty(FENSTER, cv2.WND_PROP_FULLSCREEN, cv2.WINDOW_FULLSCREEN)
		cv2.setMouseCallback(FENSTER, self._maus)
		self.buttons = []
		self.gedrueckt = None

	def _maus(self, ereignis, x, y, flags, param):
		if ereignis == cv2.EVENT_LBUTTONDOWN:
			for schluessel, x0, y0, x1, y1, _, _ in self.buttons:
				if x0 <= x <= x1 and y0 <= y <= y1:
					self.gedrueckt = schluessel

	def taste(self):
		"""Zuletzt gedrueckten Button einmalig zurueckgeben."""
		t, self.gedrueckt = self.gedrueckt, None
		return t

	def zeigen(self, titel, zeilen, inhalt=None, buttons=()):
		"""buttons: Liste (schluessel, beschriftung, farbe); farbe "gruen"/"rot"/"grau"/"blau"."""
		farben = {"gruen": (60, 140, 60), "rot": (60, 60, 160), "grau": (90, 90, 90), "blau": (150, 100, 40)}
		bild = np.full((H, W, 3), 245, np.uint8)
		bild[:44] = (45, 45, 45)
		if inhalt is not None:
			x0, y0, x1, y1 = self.INHALT
			bild[y0:y1, x0:x1] = cv2.resize(inhalt, (x1 - x0, y1 - y0)) if inhalt.shape[:2] != (y1 - y0, x1 - x0) else inhalt
		self.buttons = []
		if buttons:
			n = len(buttons)
			breite = (W - 8 * (n + 1)) // n
			for k, (schluessel, text, farbe) in enumerate(buttons):
				x0 = 8 + k * (breite + 8)
				self.buttons.append((schluessel, x0, 404, x0 + breite, 474, text, farben.get(farbe, farben["grau"])))
				cv2.rectangle(bild, (x0, 404), (x0 + breite, 474), farben.get(farbe, farben["grau"]), -1)
				cv2.rectangle(bild, (x0, 404), (x0 + breite, 474), (220, 220, 220), 2)
		pil = Image.fromarray(cv2.cvtColor(bild, cv2.COLOR_BGR2RGB))
		d = ImageDraw.Draw(pil)
		d.text((12, 8), titel, font=schrift(24, True), fill=(255, 255, 255))
		for i, z in enumerate(zeilen[:4]):
			d.text((12, 50 + i * 19), z, font=schrift(16), fill=(20, 20, 20))
		for _, x0, y0, x1, y1, text, _ in self.buttons:
			f = schrift(22 if len(self.buttons) <= 4 else 17 if len(self.buttons) <= 6 else 15, True)
			d.text(((x0 + x1) / 2 - d.textlength(text, font=f) / 2, 426), text, font=f, fill=(255, 255, 255))
		cv2.imshow(FENSTER, cv2.cvtColor(np.asarray(pil), cv2.COLOR_RGB2BGR))
		cv2.waitKey(1)


# Zwei Methoden fuer die Wellenlaengen (Auswahl beim Start):
#   "laser": 1 Ausschnitt, 2/3 Laser, 4 LED-Blauspitze, 5 Gluehlampe, 6 Speichern
#   "cfl":   1 Ausschnitt, 2 Leuchtstofflampe, 3 Laser-Kontrolle, 4 Gluehlampe, 5 Speichern
GESAMT = 5            # Anzahl Schritte der gewaehlten Methode (fuer die Titel)
LASER_GRUEN_NM = 513  # eigener gruener Laser laut Leuchtstofflampe (06.10.); DPSS-Laser: 532
LASER_ROT_NM = 650
# Farbtemperatur der Referenz-Gluehlampe (Voreinstellung im Gluehlampen-Schritt, dort mit -/+ aenderbar).
# Normale Gluehlampen 100-200 W: 2850-2950 K. Unsere 200-W-Lampe strahlt wie ~2060 K: Abgleich am
# 06.10.2026 mit Leuchtstofflampe (2700 K) und LED (5500 K) gleichzeitig, beide danach auf ~2 % genau.
# Bei einer anderen Lampe: mit einer Lampe bekannter Farbtemperatur pruefen und hier anpassen.
GLUEHLAMPE_K = 2060


def titel_setzen(methode):
	global GESAMT, TITEL_GL, TITEL_CFL
	GESAMT = 6 if methode == "laser" else 5
	TITEL_GL = "Schritt %d von %d: Glühlampe (Normkurve)" % (GESAMT - 1, GESAMT)
	TITEL_CFL = "Schritt 2 von %d: Leuchtstofflampe" % GESAMT


# --------------------------------------------------------------------------- Messhilfen
STUFEN_US = [100, 200, 500, 1000, 2000, 5000, 10000, 20000, 50000, 100000, 200000, 500000, 1000000]
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

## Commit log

2026-10-03 Spektrometer für Leuchtmittel v1.0
    Raspberry-Pi-5-Spektrometer für den Beleuchtungstechnik-Unterricht:
    Live-Spektrum 360-800 nm, Ra/R9/Farbtemperatur, Kalibrier-Assistent,
    Beamer-Ansicht. Basis PySpectrometer2 (Les Wright, Apache-2.0).
    Enthält Installationsskript, Kaufliste und die Zeichnungen des
    Raster-Grundplatten-Systems RGS v1.0.
2026-10-03 RGS-Zeichnungen entfernt: Das Gerät nutzt noch eine andere Grundplatte
    Hardware-README beschreibt jetzt allgemein Druckdateien und Aufbauhinweise;
    Kleinteile-Stückliste folgt mit den Druckdateien.
2026-10-04 Druckdateien ergänzt (3MF je Teil + Gesamtplatte, Fusion-360-Konstruktion)
    [Spektrometer_01-All.f3d, Spektrometer_01-Grundplatte.3mf, Spektrometer_01-Halter-Spektroskop.3mf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]
2026-10-04 Kaufliste auf den Original-Aufbau umgestellt, Stückliste Kleinteile
    Konkrete Produkte (Pi-5-Starter-Set, OV9281 mit Objektiv, Spektroskop,
    Gewindeeinsätze und Schrauben mit Stückzahlen), Partnerlinks als direkte
    Produktlinks. Hinweis: Display-5er-Pack derzeit nicht lieferbar.
    [Spektrometer_01-All.3mf, Spektrometer_01-All.f3d, Spektrometer_01-Halter-Spektroskop.3mf]
2026-10-04 Druckhinweis Spaltkappe: weißes PLA, glatte Druckplatte, erste Schicht 0,1 mm
2026-10-04 Kalibrier-Assistent: Bildausschnitt nach der Wellenlängen-Kalibrierung automatisch auf 360-800 nm zuschneiden
    Schritt 1 bleibt bewusst großzügig; nach Lasern/LED wird der Ausschnitt berechnet,
    die Kalibrierpunkte umgerechnet (auch gespiegelt) und die Kamera neu gestartet,
    sodass die Glühlampe bereits im endgültigen Ausschnitt gemessen wird.
2026-10-04 Glühlampen-Voreinstellung im Assistenten auf 2850 K (Abgleich am neuen Aufbau: 2871 K)
    [Spektrometer_01-All.3mf, Spektrometer_01-All.f3d, Spektrometer_01-Tunnel.3mf]
2026-10-04 Fotos und Screenshots ergänzt, Messwerte nach Neukalibrierung aktualisiert
    Gerät, Draufsicht, Spaltkappe; Display-Spektren Glühlampe/LED 5000 K/8500 K;
    Beamer-Ansicht. Genauigkeit: 5000 K -> 4990 K, 8500 K -> 8440 K, Glühlampe 2860 K.
    Hinweis zur Winkelabhängigkeit von LED-Leuchten.
2026-10-04 Druckdateien: Lichttunnel aktualisiert, doppelte Gesamtplatte entfernt
    Spektrometer_01_All.3mf (alter Export) ersetzt durch Spektrometer_01-All.3mf.
    [Spektrometer_01-Tunnel.3mf, Spektrometer_01_All.3mf]
2026-10-06 Kalibrierung mit Leuchtstofflampe, Methodenwahl, Glühlampen-Abgleich
    - Kalibrier-Assistent: Beim Start Wahl zwischen Leuchtstofflampe und Laser + LED
    - Leuchtstofflampe: Linien Hg 405/436, Tb 488, Hg 546, Eu 611/709 nm automatisch
    erkennen und zuordnen, Spiegelung prüfen, Restfehler je Linie, optionale Laser-Kontrolle
    - specFunctions: ab 3 Punkten Ausgleichsparabel (auch in readcal statt Polynom 3. Grades)
    - Glühlampen-Voreinstellung GLUEHLAMPE_K = 2060 K (Abgleich auf Energiesparlampe 2700 K
    und LED 5500 K), grüner Laser LASER_GRUEN_NM = 513 nm
    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
